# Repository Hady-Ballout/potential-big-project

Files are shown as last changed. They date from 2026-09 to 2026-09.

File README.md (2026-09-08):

# Interphone project

ESP32 door-entry prototype with QR visitor access, a resident web app, a Supabase backend, and hardware designs.

- [Software, firmware, and setup instructions](interphone/README.md)
- [Software plan](interphone/docs/PLAN.md)
- [Hardware brief](interphone/docs/PROJECT_CONTEXT.md)

The root folder contains the Fritzing drawings, exported wiring netlists, component list, and shopping list. Hardware operation has been verified; cloud-to-hardware integration and video/audio calling remain to be completed.

Local credentials, dependency folders, generated builds, and the discard folder are excluded from version control. Copy the supplied example configuration files when setting up a new machine.

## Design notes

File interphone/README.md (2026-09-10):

# Interphone

Cloud-connected door entry for apartment buildings. A visitor scans the QR sticker at the door,
picks an apartment, and the resident sees and hears them on their phone and taps **Unlock**.
An ESP32 at the door pulses a relay that opens a 12 V lock.

Full design: [docs/PLAN.md](docs/PLAN.md). Hardware brief: [docs/PROJECT_CONTEXT.md](docs/PROJECT_CONTEXT.md).

```
visitor phone ──HTTPS──▶ Supabase (Postgres + edge functions + realtime) ◀──push/realtime── resident PWA
                                  ▲ 1 s HTTPS poll, device token
                            ESP32 DevKit V1 firmware (relay, buzzer, LED, button)
```

## What is done (Phase 1 to 3)

| Piece | Where | Status |
|---|---|---|
| Firmware state machine, buzzer patterns, pin maps | `firmware/src` | done, 12 native unit tests pass |
| Wi-Fi + backend polling on a FreeRTOS task | `firmware/src/net_client.cpp` | done, compile-checked; needs the real build (`pio run`) |
| Wokwi breadboard simulation | `firmware/wokwi` | done |
| Database schema, RLS, demo seed | `supabase/migrations`, `supabase/seed.sql` | done, applied + RLS tested on Postgres 16 |
| Edge functions `ring`, `respond`, `device-poll` | `supabase/functions` | done, `deno check` clean |
| Virtual door controller (no hardware) | `tools/virtual-device` | done |
| Visitor page + resident app + push (minimal) | `web/` | done, see `web/README.md` |
| Door sticker QR generator | `tools/make-qr` | done |
| WebRTC video/audio + private signaling | `web/src/lib/webrtc.ts`, `supabase/functions/call-config` | done; needs TURN credentials and two-device field test |

## Quick start

### 1. Firmware on your laptop (no hardware)

```
cd firmware
pio test -e native          # unit tests for the door logic
pio run  -e esp32devkit     # full ESP32 build (needs the PlatformIO ESP32 toolchain, downloads once)
```
Then follow `firmware/wokwi/README.md` to press the button and watch the relay in the browser.

Serial keys while it runs (Wokwi or real board): `u` unlock, `d` deny, `s` status.

### 2. Backend locally

Requires Docker Desktop. The Supabase CLI runs through npx (or `scoop install supabase`).
```
npx supabase start                                    # local Postgres, auth, functions, studio (pulls images once)
npx supabase db reset                                 # applies migrations + seed.sql
npx supabase functions serve --env-file supabase/.env # (copy supabase/.env.example first; VAPID keys optional)
```
Demo data from `seed.sql`: building **demo-building** with apartments 1A–3A,
resident **demo@interphone.local / demo1234** (1A), device token **demo-device-token-change-me**.

### 3. See a cloud unlock reach the door

Terminal A — the door:
```
cd tools/virtual-device
SUPABASE_FUNCTIONS_URL=http://127.0.0.1:54321/functions/v1 DEVICE_TOKEN=demo-device-token-change-me node index.mjs
```
Terminal B — a visitor rings 1A, then the resident unlocks:
```
F=http://127.0.0.1:54321/functions/v1
curl "$F/ring?building=demo-building"                        # apartments + door_online
curl -X POST $F/ring -H 'content-type: application/json' \
     -d '{"building":"demo-building","apartment_id":"00000000-0000-0000-0000-00000000a001","note":"DHL"}'
# -> {"visit_id":"...","status":"ringing"}

# log in as the resident to get a JWT (anon key is printed by `supabase start`)
TOKEN=$(curl -s -X POST http://127.0.0.1:54321/auth/v1/token?grant_type=password \
  -H "apikey: $ANON_KEY" -H 'content-type: application/json' \
  -d '{"email":"demo@interphone.local","password":"demo1234"}' | jq -r .access_token)

curl -X POST $F/respond -H "authorization: Bearer $TOKEN" -H 'content-type: application/json' \
     -d '{"visit_id":"<visit_id from above>","action":"unlock"}'
```
Within a second terminal A prints `door -> UNLOCKING *** RELAY ON ***`.
To do the same with the simulated ESP32 instead, put your project's functions URL and the device
token in `firmware/secrets.ini` (see `secrets.ini.example`) and run Wokwi in VS Code — the Wokwi
browser editor cannot reach a `localhost` backend, so for the browser use a deployed Supabase project.

### 4. Web app: scan, ring, unlock

```
cd web && npm install && cp .env.example .env.local   # fill VITE_SUPABASE_ANON_KEY from `npx supabase status`
npm run dev                                           # http://localhost:5173
```
Visitor page: http://localhost:5173/d/demo-building. Resident app: http://localhost:5173/app
(demo@interphone.local / demo1234). With the virtual device from step 3 running, tapping **UNLOCK**
prints `RELAY ON` in terminal A. Door sticker: `node tools/make-qr/index.mjs demo-building http://<laptop LAN IP>:5173`.
Details, phone testing and push setup: `web/README.md`.

### 5. Deploy the backend to Supabase cloud

```
supabase link --project-ref <ref>
supabase db push
supabase functions deploy ring respond device-poll call-config
supabase secrets set --env-file supabase/.env
```

## API (edge functions)

| Function | Auth | Purpose |
|---|---|---|
| `GET /ring?building=slug` | none | apartments list + door online flag (visitor page) |
| `GET /ring?visit=id` | none | visit status, visitor polls while waiting |
| `POST /ring` | none, rate-limited | create a visit, push residents |
| `POST /respond` | resident JWT | `answer`, `unlock`, `deny` a visit; `unlock` with `apartment_id` for self-entry |
| `POST /device-poll` | `x-device-token` | door controller heartbeat + pending commands |

## Repository layout

```
firmware/   PlatformIO project (ESP32 DevKit V1 default, ESP32-S3 alternate, native tests)
supabase/   migrations, seed, edge functions, config
web/        visitor page + resident app (Vite + React), see web/README.md
tools/      virtual-device (fake door controller), make-qr (door sticker), docker-pull-host (image pull workaround)
docs/       PLAN.md, PROJECT_CONTEXT.md (hardware)
```

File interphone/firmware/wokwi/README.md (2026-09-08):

# Wokwi simulation

Two ways to run the firmware with no hardware.

## A. wokwi.com in the browser (no toolchain needed)

1. Run `python pack_for_browser.py` in this folder. It creates `browser-project/` with a
   flat copy of the firmware, a `sketch.ino`, `libraries.txt` and this `diagram.json`.
2. Go to https://wokwi.com -> New Project -> ESP32.
3. In the Wokwi editor, use the file menu to upload every file from `browser-project/`
   (or drag-and-drop them). Overwrite `sketch.ino` and `diagram.json` when asked.
4. Press the green Start button. In the serial monitor you should see the banner and
   `[door] -> IDLE` (standalone mode: no backend URL is configured, so the device counts as online).
5. Click the green pushbutton: LED2 blinks fast and the buzzer plays the ring pattern,
   then after 1 s the relay clicks, LED1 (on the relay contacts) lights for 3 s, LED2 is solid.
6. Type `u` in the serial monitor to simulate a cloud unlock, `d` for deny, `s` for status.

## B. Wokwi extension in VS Code (uses the real PlatformIO build)

1. Install the "Wokwi Simulator" VS Code extension and request the free license key it asks for.
2. `pio run -e esp32devkit`
3. F1 -> "Wokwi: Start Simulator" (it reads `wokwi.toml`).

## Differences from the real breadboard

- Wokwi has no NPN transistor or diode parts, so the buzzer is driven straight from GPIO18.
  On the real board GPIO18 -> 1k -> NPN base, buzzer on the collector with the 1N4007 flyback
  diode. The firmware is identical: a HIGH on the pin means sound in both cases.
- Wokwi has no 30-pin "DevKit V1" board with real 5V on VIN; power rails are logical here.
- LED1 on the relay's NO contact stands in for the 12V lock, exactly like the bench build.

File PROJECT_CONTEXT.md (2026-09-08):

# Interphone Project Two

Door entry / interphone controller built on an ESP32 dev board. Breadboard prototype
stage. Source of truth for the wiring is the Fritzing sketch and its exported netlist.

Last updated: 2026-09-01

---

## 1. What it does

A visitor or resident presses a button. The controller sounds a buzzer, shows status on
an LED, and fires a relay that would drive the electric door strike. On the current
breadboard build the strike is replaced by a resistor and LED on the relay contacts so
the actuation is visible on the bench.

Four functional blocks:

1. **Button input.** Tactile pushbutton with a 10k pull-up to 3V3. Active low: the GPIO
   reads HIGH at idle and LOW when pressed.
2. **Relay output.** GPIO drives the relay module IN pin. COM sits on the 5V rail, NO
   feeds 330R into an LED to ground. NC unconnected.
3. **Buzzer driver.** GPIO through 1k into the base of an NPN. Emitter to ground,
   collector to the buzzer, buzzer other side to the 5V rail, flyback diode across it.
   Low side switch.
4. **Status LED.** GPIO through 330R into an LED to ground, driven directly.

---

## 2. Bill of materials (from the netlist)

| Ref | Component | Qty |
|---|---|---|
| M1 | ESP32 dev board | 1 |
| Part1 | KY-019 5V relay module | 1 |
| J1 | Buzzer | 1 |
| D1 | Rectifier diode (1N4007) | 1 |
| Q1 | NPN transistor (2N2222 / BC547) | 1 |
| S1 | Tactile pushbutton, 4 pin | 1 |
| LED1 | Red LED 5mm (relay indicator) | 1 |
| LED2 | Red LED 5mm (status) | 1 |
| R1 | 330R (LED1 series) | 1 |
| R2 | 330R (LED2 series) | 1 |
| R3 | 10k (button pull-up) | 1 |
| R4 | 1k (transistor base) | 1 |
| Breadboard1 | RSR 03MB102 breadboard, 830 point | 1 |

12 components plus the breadboard.

---

## 3. Power rails

| Rail | Source | Feeds |
|---|---|---|
| 3V3 | Board 3V3 pins | R3 pull-up |
| 5V | Board 5V / VIN pin | Relay coil VCC, relay COM, buzzer, D1 cathode |
| GND | Board GND pins, both breadboard minus rails tied together | Everything |

Current budget on the 5V rail is roughly 70 to 80 mA for the relay coil plus about
30 mA for the buzzer. That is inside USB limits but coil inrush coinciding with a Wi-Fi
transmit burst is the likely cause of any brownout resets. Mitigation: 1000uF bulk cap
on the rail, 100nF decoupling near the relay and buzzer, and a 5V 2A wall adapter rather
than a laptop port.

---

## 4. Pin mapping

### 4a. Original design: ESP32-S3-DevKitC-1-N8R8

The Fritzing part numbers pins DIP style: 1 to 22 down the left header (J1), then 23 to
44 back up the right header (J3). Verified against the Espressif v1.1 header tables.

| Netlist pin | Actual pin | Use |
|---|---|---|
| 1, 2 | 3V3, 3V3 | 3V3 rail |
| 21 | 5V | 5V rail |
| 22, 23, 24, 44 | GND x4 | ground rails |
| 5 | GPIO5 | Relay IN |
| 6 | GPIO6 | Status LED via R2 |
| 11 | GPIO18 | Buzzer via R4 into Q1 base |
| 27 | GPIO21 | Pushbutton input |

GPIO5, 6, 18 and 21 are all plain I/O on the S3. No strapping, boot, USB or PSRAM
conflicts. GPIO43 and 44 are untouched, so UART0 and flashing stay intact.

**Status: verified functional as drawn.**

### 4b. Fallback: classic ESP32 DevKit V1 (ESP32-WROOM-32, 30 pin)

Only needed if the S3 stays out of stock. Different chip, so the netlist pin mapping
does not carry over and the Fritzing part must be swapped.

| Function | S3 | DevKit V1 |
|---|---|---|
| Relay IN | GPIO5 | GPIO5 |
| Status LED | GPIO6 | GPIO4 |
| Buzzer | GPIO18 | GPIO18 |
| Button | GPIO21 | GPIO19 |

Constraints on the classic ESP32: avoid GPIO6 to 11 (flash), avoid GPIO0, 2, 12 and 15
(strapping), GPIO34 to 39 are input only. The 5V pin is labelled VIN and sits around
4.6 to 4.7V on USB power after the protection diode, which is marginal but usually
enough for the relay coil.

---

## 5. Design notes and things to verify on hardware

- **Relay COM on the logic 5V rail.** Correct for the bench stand-in. For the real
  installation, COM goes to the door strike supply and stays isolated from the logic
  side. Do not carry this over to the final build.
- **Clone boards.** If the board is a clone rather than a genuine Espressif DevKitC-1
  (tell by the connector: genuine is Micro-B, clones often use dual USB-C), meter the
  header before wiring. Confirm the 5V pin and all four GND pins, since the rails hang
  off them.
- **Relay trigger threshold.** Most KY-019 boards trigger fine from a 3.3V GPIO. If it
  is stubborn, that is the threshold, not the wiring.
- **Buzzer type.** Circuit assumes an active 5V buzzer. A passive one needs a PWM tone
  on the GPIO instead of a simple HIGH.
- **Arduino IDE settings for S3 N16R8 clones:** board = ESP32S3 Dev Module, flash 16MB,
  PSRAM = OPI. Wrong PSRAM setting causes boot loops.

---

## 6. Procurement

Local supplier: Electroslab (Lebanon), also reachable on WhatsApp.

| Board | Price | Status |
|---|---|---|
| ESP32-S3 N16R8 dev board (clone, dual USB-C) | $12.00 | Out of stock, notify list |
| ESP32 DevKit V1 (WROOM-32, 30 pin) | $9.00 | In stock |

Full prototype kit including spares, debug gear and a second board estimates at $110 to
$195 cash USD locally, or $90 to $155 if the lab already has a multimeter. Ordering the
dev boards from AliExpress saves roughly $25 but adds three to six weeks.

Cables: genuine DevKitC-1 is Micro-B, the Electroslab S3 clone is USB-C, the DevKit V1
is Micro-B. Data cables, not charge only.

---

## 7. Optional expansion

- **Real door hardware:** 12V electric strike, 12V 2A supply, spade or screw terminals.
  Roughly $35 to $80. Keep that supply completely separate from the ESP32 5V rail.
- **On-device QR scanning:** requires an ESP32-S3 board with a camera. The DevKitC-1 has
  no imager. If the QR is scanned on the visitor's phone instead, no extra hardware is
  needed and the DevKit V1 is sufficient.

---

## 8. PCB Pilot coverage

Every component in this design exists in the PCB Pilot registry:

`esp32`, `relay_module`, `buzzer`, `diode`, `led`, `bjt_npn`, `pushbutton`, `resistor`.

The `esp32` kind is 12 pins, fixed order: 3V3, GND, VIN, EN, GPIO2, GPIO4, GPIO5,
GPIO13, GPIO18, GPIO19, GPIO21, GPIO22. Flagged `mcu` and `wiringOnly`, so it is
excluded from the SPICE deck but participates in layout and the topology rules.
`relay_module` pin order is VCC, GND, IN, COM, NO, NC, matching the KY-019.

**Registry gap:** there is no `esp32_s3` kind. Only classic ESP32, Arduino Uno and
Raspberry Pi are available under `mcu`. The `esp32` kind also exposes only 8 GPIOs,
which is enough for this project but tight. Worth logging as a product item given how
common S3 boards are in student work.

---

## 9. Open items

- [ ] Confirm S3 restock date with Electroslab, or commit to the DevKit V1 fallback
- [ ] Meter the board header (5V pin, all GND pins) before wiring
- [ ] Decide whether QR scanning happens on device or on the visitor's phone
- [ ] Confirm with instructor whether the demo needs a real strike or the LED stand-in
- [ ] Firmware: button debounce, relay pulse duration, buzzer pattern, Wi-Fi provisioning
- [ ] Run the design through PCB Pilot `validate_circuit` as a toolchain smoke test

---

## 10. Files

| File | What it is |
|---|---|
| `Interphone_Project_two_netlist.xml` | Fritzing netlist export, source of truth for wiring |
| `Interphone Project two.fzz` | Fritzing sketch |
| `PROJECT_CONTEXT.md` | This file |

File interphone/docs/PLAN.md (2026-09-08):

# Interphone software plan — build everything before the hardware arrives

## Context

The hardware for the ESP32 door-entry controller is ordered but not here yet (DevKit V1, KY-019 relay, 12V solenoid lock, buzzer, LEDs — see `Component List.xlsx`). The goal is to start the software now and have as much as possible working, tested and demoable by the time the parts arrive, so hardware bring-up becomes a short checklist rather than the start of development.

Scope confirmed with Hady: **everything from the moment the visitor scans the QR code** —

1. Visitor scans a QR sticker at the building door → a web page opens on their phone.
2. Visitor picks the apartment they're visiting → the resident gets a push notification.
3. Resident opens the app, **sees and hears the visitor (video + audio)**, and taps Unlock.
4. The ESP32 at the door pulses the relay → the 12V lock opens; buzzer + LED give feedback at the door.

Decisions: PlatformIO in VS Code for firmware, Wokwi in the browser for simulation, Supabase for the backend, an installable web app (PWA) with push notifications for residents. Purpose: portfolio / startup prototype, so it should look and behave like a product, and the architecture should have a credible path to a real multi-building deployment.

Key design choice for video/audio: **the visitor's own phone is the intercom panel.** They already scanned the QR with it, so a browser-to-browser WebRTC call (visitor page ↔ resident PWA) gives video + audio with zero extra hardware. The DevKit V1 has no camera or mic, and an ESP32-CAM would give worse video for more work. A door-mounted camera can be a later product phase.

---

## Architecture

```
 Visitor phone                 Supabase (cloud)                 Resident phone
 ┌──────────────┐    HTTPS     ┌─────────────────────┐   push    ┌──────────────┐
 │ /d/{building}│─────────────▶│ Edge fn: ring       │──────────▶│ Resident PWA │
 │ pick apt,    │              │ Postgres + RLS      │  realtime │ incoming call│
 │ ring, camera │◀════════════▶│ Realtime (signaling)│◀═════════▶│ video+audio  │
 └──────────────┘   WebRTC     │ Edge fn: unlock     │           │ [Unlock]     │
        ▲ (P2P via STUN/TURN)  │ Edge fn: device-poll│           └──────────────┘
        └──────────────────────│ door_commands table │
                               └─────────┬───────────┘
                                         │ HTTPS poll (1 s), device token
                               ┌─────────▼───────────┐
                               │ ESP32 DevKit V1     │  GPIO5 relay → 12V lock
                               │ firmware            │  GPIO18 buzzer, GPIO4 LED
                               │ (Wokwi until real)  │  GPIO19 button (exit/test)
                               └─────────────────────┘
```

ESP32 ↔ backend uses **short polling over HTTPS** first (1 s interval, ≤1 s unlock latency). Reasons: trivial firmware, works in Wokwi's simulated Wi-Fi, no websocket/Phoenix protocol on the microcontroller. Upgrading to Supabase Realtime or MQTT later is a contained change inside `net_client`.

Multi-apartment from day one: one ESP32 per building door, many apartments per building, many residents per apartment. The visitor page is per building (`/d/{building_slug}`), which is what the QR encodes.

---

## Repository layout (new monorepo `interphone/` inside "Potential Big Project")

```
interphone/
  README.md
  firmware/                      PlatformIO project
    platformio.ini               envs: esp32devkit (default), esp32s3 (kept), native (tests)
    include/pins.h               #ifdef BOARD_DEVKIT_V1 / BOARD_ESP32_S3 pin maps
    include/config.h             timings, poll interval, Wi-Fi/device creds via build flags
    src/main.cpp                 setup/loop only: wires modules together
    src/door_controller.{h,cpp}  pure logic state machine (no Arduino deps) — unit-tested
    src/buzzer.{h,cpp}           non-blocking pattern player (ring / unlocked / denied / error)
    src/net_client.{h,cpp}       Wi-Fi connect, poll device-poll fn, ack commands, heartbeat
    src/hal.h                    tiny interface (digitalWrite/millis) so logic is mockable
    test/test_door_controller/   Unity tests run on the laptop (pio test -e native)
    wokwi/diagram.json           exact breadboard: DevKit V1, KY-019, buzzer+NPN+diode, LEDs, button
    wokwi/wokwi.toml
  supabase/
    config.toml
    migrations/0001_schema.sql   tables + RLS
    functions/ring/              public: create visit, notify residents
    functions/unlock/            resident-auth: insert door_command
    functions/device-poll/       device-token auth: return pending commands, record heartbeat
    functions/send-push/         Web Push (VAPID) helper used by ring
    seed.sql                     demo building, 3 apartments, 1 device, 1 resident
  web/                           Vite + React + TypeScript PWA (one app, two entry routes)
    src/routes/visitor/          /d/:slug → choose apartment → ringing → call → door opened
    src/routes/resident/         /app → login (magic link) → incoming visit → video → Unlock → history
    src/lib/supabase.ts, webrtc.ts, push.ts
    public/sw.js                 service worker: push + PWA install
  tools/
    virtual-device/              Node script that polls exactly like the firmware and prints UNLOCK
    make-qr/                     generates the door QR PNG for a building slug
```

---

## Data model (Supabase Postgres)

| Table | Key columns | Notes |
|---|---|---|
| `buildings` | id, slug, name | slug is what the QR encodes |
| `apartments` | id, building_id, label ("3B"), sort_order | shown on visitor page |
| `profiles` | id (= auth.users.id), display_name | |
| `apartment_members` | apartment_id, profile_id, role | who can unlock which door |
| `devices` | id, building_id, name, token_hash, last_seen_at | one per door controller |
| `visits` | id, apartment_id, status, visitor_note, created_at, answered_by, ended_at | status: `ringing → answered → unlocked / denied / expired` |
| `door_commands` | id, device_id, visit_id, action ("unlock"), created_at, delivered_at, expires_at | firmware acks by setting delivered_at; expires after 30 s |
| `push_subscriptions` | profile_id, endpoint, keys | Web Push targets |

RLS: residents read/write only visits for apartments they belong to; visitor page uses the `ring` edge function (service role, rate-limited by IP + apartment); devices never touch the DB directly — only `device-poll` with a hashed token.

WebRTC signaling: a Supabase Realtime **Broadcast** channel per visit (`visit:{id}`) carries SDP offers/answers and ICE candidates. STUN: Google public. TURN: Metered.ca free tier (needed for phones on carrier NAT); coturn on a VPS later.

---

## Firmware behaviour (door_controller state machine)

```
IDLE ──button pressed (debounced 30 ms)──▶ LOCAL_RING  (buzzer ring pattern, LED blink; for bench demo also unlocks after 1 s)
IDLE ──unlock command from cloud───────▶ UNLOCKING   (relay HIGH for UNLOCK_MS=3000, buzzer "unlocked" chirp, LED solid)
UNLOCKING ──timer──────────────────────▶ COOLDOWN    (relay LOW, ignore new unlocks for 1 s)
COOLDOWN ──timer───────────────────────▶ IDLE
any ──Wi-Fi lost──────────────────────▶ OFFLINE      (LED slow blink; button still works locally) ──reconnected──▶ IDLE
```

Everything non-blocking (`millis()`-based), no `delay()` in loop. The state machine takes `now_ms` and events as plain C++ so `pio test -e native` runs it on the laptop with no board.

Pin map (`pins.h`), DevKit V1 default per `PROJECT_CONTEXT.md` §4b: relay GPIO5, LED GPIO4, buzzer GPIO18, button GPIO19 (INPUT_PULLUP, active low). S3 map kept behind `#ifdef` so the original design isn't lost.

---

## Phases (each ends with something you can see working)

### Phase 0 — Setup (½ day)
Install VS Code + PlatformIO, Node 20, Supabase CLI; create Supabase project and Wokwi account; `git init` the monorepo. Commit the existing `PROJECT_CONTEXT.md` into `docs/` and update it: DevKit V1 is now primary, S3 is the alternate, `interphone 3.fzz` listed.

### Phase 1 — Firmware core in Wokwi (1–2 days) ← **"see the relay click today"**
`pins.h`, `door_controller`, `buzzer`, `main.cpp`, `diagram.json`. Press the simulated button → buzzer sounds, LED blinks, relay clicks and its LED lights for 3 s. Native unit tests for debounce, unlock pulse length, cooldown, and re-trigger rejection.

### Phase 2 — Backend + cloud unlock (2 days)
`0001_schema.sql`, RLS, `seed.sql`, edge functions `ring`, `unlock`, `device-poll`. `tools/virtual-device` polls and prints UNLOCK. Then `net_client` in firmware: Wokwi ESP32 joins `Wokwi-GUEST`, polls `device-poll` over HTTPS. Demo: `curl` the `unlock` function → simulated relay fires within a second.

### Phase 3 — Visitor page + resident PWA + push (3–4 days)

_Status (2026-09-05): built in a minimal form — email+password login instead of magic link, no visit history yet, video deferred to Phase 4. See `web/README.md`._
Visitor: `/d/demo-building` → apartment grid → "Ring" → "Waiting for resident…" → status updates via Realtime. Resident: magic-link login, installable PWA, push notification on ring, incoming-visit screen with Unlock / Deny, visit history. `make-qr` produces the sticker PNG. Demo: scan QR on a phone, ring, get push on another phone, tap Unlock, Wokwi relay fires.

### Phase 4 — Video + audio (2–3 days)
`webrtc.ts`: visitor page requests camera+mic on "Ring"; on resident answer, exchange SDP/ICE over the `visit:{id}` Broadcast channel; resident sees/hears visitor (one-way video, two-way audio). Hang-up on unlock/deny/expiry. TURN credentials fetched from an edge function so keys aren't in the client.

### Phase 5 — Product hardening (ongoing)
Device online/offline indicator from `last_seen_at`; visit auto-expire after 60 s; rate-limit `ring`; audit log of unlocks; Wi-Fi provisioning via captive portal (WiFiManager) instead of compiled-in creds; OTA updates; building admin screen to manage apartments/residents.

### When the components arrive — bring-up checklist (not software, but planned now)
- Meter the DevKit V1 header (VIN, all GNDs) before wiring.
- Flash the same firmware with `-e esp32devkit`; only `pins.h` matters.
- Verify KY-019 triggers from 3.3 V GPIO; verify buzzer is active (it is per shopping list).
- **12V lock wiring:** lock supply (12V/1A adapter) is completely separate from ESP32 5V. Relay COM → +12V, NO → lock +, lock − → 12V GND. **Add a 1N4007 flyback diode across the solenoid** (cathode to +12V) — the shopping list has the diodes but `PROJECT_CONTEXT.md` only puts one on the buzzer. The lock is a solenoid and will spike the relay contacts without it.
- Watch for brownout resets on relay inrush + Wi-Fi burst (1000 µF bulk cap, wall adapter not laptop USB).

---

## Verification

- **Firmware logic:** `pio test -e native` — debounce, 3 s unlock pulse, cooldown, offline behaviour.
- **Firmware build:** `pio run -e esp32devkit` compiles clean; upload `.pio/build/esp32devkit/firmware.bin` + `diagram.json` to wokwi.com and drive the button.
- **Backend:** `supabase start` locally, `supabase db reset` applies migrations + seed; `supabase functions serve`; `curl` each function; RLS checked by attempting cross-apartment unlock as a second seeded user (must fail).
- **End-to-end without hardware:** virtual-device running → visitor page on phone → resident PWA on second phone/browser → Unlock → virtual device prints UNLOCK; then the same with Wokwi instead of virtual device.
- **Video:** two phones on different networks (Wi-Fi vs mobile data) to prove TURN works.

## Out of scope for now
Door-mounted camera (ESP32-CAM / S3-CAM), native iOS/Android apps, payments/subscriptions, multi-door per building, NFC/keypad. All fit the schema later without redesign.

## Open questions to settle during Phase 0 (not blocking)
- Physical button at the door: keep as a plain "exit/test" button, or make it a fallback bell that rings *all* apartments? (Plan assumes exit/test.)
- Web framework: plan assumes Vite + React + TypeScript; SvelteKit or Next.js are equally fine if you prefer.

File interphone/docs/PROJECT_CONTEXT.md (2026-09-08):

# Interphone — hardware brief

Door entry / interphone controller built on an ESP32 dev board. Breadboard prototype stage;
the software is being built ahead of the hardware (see PLAN.md).

Last updated: 2026-09-02. Supersedes the copy in the parent folder.

---

## 1. What it does

A visitor rings from their phone (QR at the door) or presses the door button. The controller
sounds a buzzer, shows status on an LED, and fires a relay that drives the electric lock. On the
breadboard build the lock is replaced by a resistor and LED on the relay contacts so the
actuation is visible on the bench.

Four functional blocks:

1. **Button input.** Tactile pushbutton with a 10k pull-up to 3V3. Active low.
2. **Relay output.** GPIO drives the relay module IN pin. Bench: COM on the 5V rail, NO feeds
   330R into an LED to ground. Real door: COM on +12V, NO to the lock (see §5).
3. **Buzzer driver.** GPIO through 1k into the base of an NPN. Emitter to ground, collector to the
   buzzer, buzzer other side to the 5V rail, flyback diode across it. Low-side switch.
4. **Status LED.** GPIO through 330R into an LED to ground, driven directly.

---

## 2. Bill of materials

What was actually ordered (`Component List.xlsx` / `Interphone_Shopping_List_v2.pdf`, $32.51,
BEC + Electroslab):

| Ref | Component | Qty |
|---|---|---|
| M1 | **ESP32 DevKit V1 (30-pin, WROOM-32)** | 1 |
| Part1 | KY-019 5V relay module | 2 (1 spare) |
| J1 | Active buzzer 5V | 2 |
| D1 | 1N4007 rectifier diode | 10 |
| Q1 | NPN transistor 2SC2061 | 2 |
| S1 | Tactile pushbutton 12×12 | 5 |
| LED1, LED2 | Red LED 5mm | 5 |
| R1, R2 | 330R | 2 |
| R3 | 10k | 1 |
| R4 | 1k | 1 |
| — | 12V solenoid door lock 55×28×30 | 1 |
| — | 12V / 1A wall adapter + 2× barrel jack | 1 |
| — | Breadboard 830, jumper wire, Micro-USB cable | — |

The ESP32-S3 (original design) was out of stock; the DevKit V1 is now the primary board.

---

## 3. Power rails

| Rail | Source | Feeds |
|---|---|---|
| 3V3 | Board 3V3 pin | R3 pull-up |
| 5V | Board VIN pin (USB) | Relay coil VCC, relay COM (bench only), buzzer, D1 cathode |
| 12V | Wall adapter | **Lock only**, via the relay contacts. Never tied to the ESP32 rails except GND. |
| GND | Board GND pins + adapter minus | Everything |

5V rail budget: ~70–80 mA relay coil + ~30 mA buzzer. Coil inrush during a Wi-Fi burst is the
likely cause of any brownout reset. Mitigation: 1000 µF bulk cap on the rail, 100 nF near the relay
and buzzer, and a wall adapter rather than a laptop USB port. On the DevKit V1, VIN sits around
4.6–4.7 V on USB after the protection diode — marginal but usually enough for the KY-019.

---

## 4. Pin mapping (matches `firmware/src/pins.h`)

| Function | DevKit V1 (primary) | ESP32-S3 (alternate) |
|---|---|---|
| Relay IN | GPIO5 | GPIO5 |
| Status LED | GPIO4 | GPIO6 |
| Buzzer (NPN base) | GPIO18 | GPIO18 |
| Button (active low) | GPIO19 | GPIO21 |

DevKit V1 constraints: avoid GPIO6–11 (flash), GPIO0/2/12/15 (strapping); GPIO34–39 input only.
S3 notes: GPIO43/44 untouched so UART0 and flashing stay intact. Arduino settings for S3 N16R8
clones: board = ESP32S3 Dev Module, flash 16MB, PSRAM = OPI.

Fritzing: `interphone 3.fzz` (2026-08-28) is the sketch with the DevKit V1 part;
`Interphone Project two.fzz` + `_netlist.xml` are the S3 version.

---

## 5. Real lock wiring (when the demo moves off the bench)

```
12V adapter +  ──── relay COM
relay NO       ──── lock +
lock −         ──── 12V adapter −  ──── ESP32 GND (common ground only)
1N4007 across the lock: cathode (band) to lock +, anode to lock −
```
- **The flyback diode across the solenoid is mandatory.** The shopping list has ten 1N4007s;
  the original brief only put one on the buzzer. Without it the coil kick arcs the relay contacts
  and can reset the ESP32.
- The 12V supply never touches the ESP32 5V/3V3 rails. Relay contacts are the isolation.
- A 12V solenoid lock draws ~0.5–1 A while energised; the 1 A adapter is at its limit. Keep
  `UNLOCK_MS` at 3 s or less (firmware default) and don't hold it.
- Relay COM on the logic 5V rail is a bench convenience only. Do not carry it to the final build.

---

## 6. Bring-up checklist (hardware arrival)

- [ ] Meter the DevKit V1 header: VIN, 3V3, all GND pins, before wiring anything.
- [ ] `pio run -e esp32devkit -t upload`, open the serial monitor, confirm the banner and `-> IDLE`.
- [ ] Press the button: ring pattern, LED blink, relay click, LED1 3 s.
- [ ] Type `u` in the serial monitor: same without the button.
- [ ] Confirm the KY-019 triggers from the 3.3 V GPIO. If not, it's the module threshold, not wiring.
- [ ] Confirm the buzzer is active (it should be; passive needs `tone()` — see `buzzer.h`).
- [ ] Put Wi-Fi + device token in `firmware/secrets.ini`, watch `[net] backend online`, unlock from the app.
- [ ] Watch for resets when the relay fires during Wi-Fi traffic → add the bulk cap.
- [ ] Only then wire the 12V lock per §5.

---

## 7. Procurement notes

Electroslab (Lebanon, WhatsApp) — DevKit V1 $9 in stock; S3 N16R8 clone $12 out of stock.
BEC — everything else. Cables: DevKit V1 is Micro-B, data cable not charge-only.

## 8. Optional expansion

- Door camera: needs an ESP32-S3 with camera or a separate cam. The product design instead uses
  the visitor's own phone camera via WebRTC (PLAN.md Phase 4), so no door camera is required.
- NFC / keypad / second door: fit the schema (`devices` per building) without redesign.

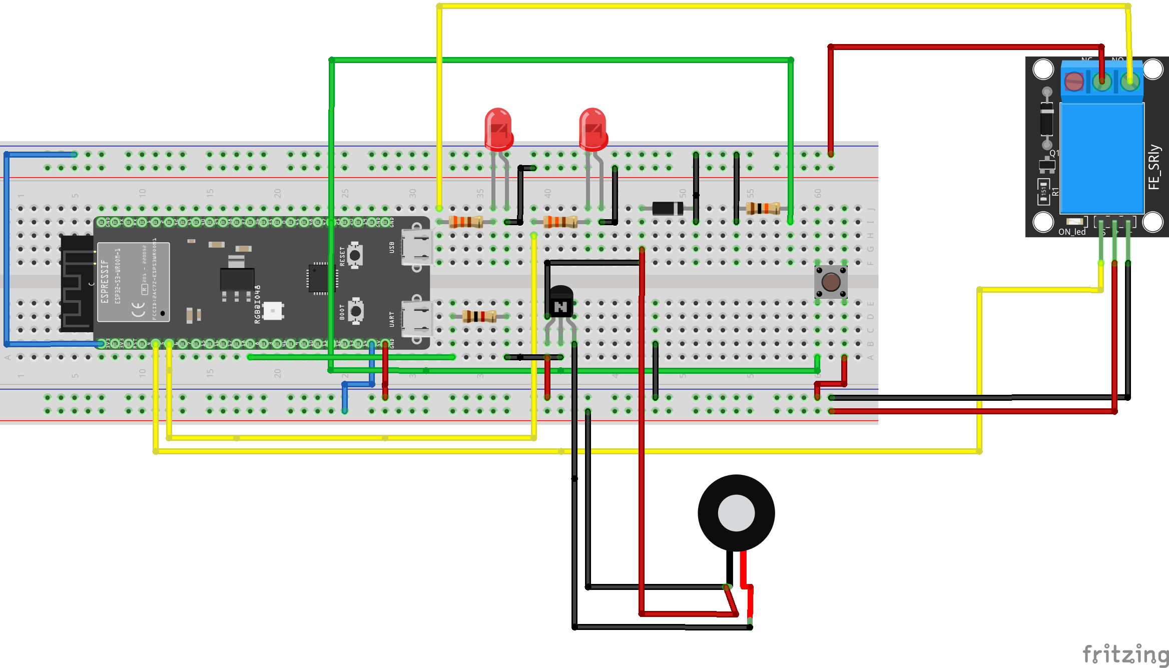
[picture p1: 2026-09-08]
Interphone Project one_bb.png

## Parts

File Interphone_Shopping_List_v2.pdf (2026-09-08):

# | Component | Qty | Unit Price ($) | Line Total ($)

1 | 12V Solenoid Door Lock (55×28×30 mm) | 1 | $7.00 | $7.00
2 | ESP32 DevKit V1 (30-pin, WROOM-32) | 1 | $9.00 | $9.00
3 | Active Buzzer (5 V) | 2 | $0.33 | $0.66
4 | NPN Transistor 2SC2061 (80 V, 0.7 A) | 2 | $0.60 | $1.20
5 | Rectifier Diode 1N4007 (5-pack) | 2 | $0.25 | $0.50
6 | Red LED 5 mm (5-pack) | 1 | $0.20 | $0.20
7 | Resistor 330 Ω, 0.25 W | 2 | $0.10 | $0.20
8 | Resistor 10 kΩ, 0.25 W | 1 | $0.10 | $0.10
9 | Resistor 1 kΩ, 0.25 W | 1 | $0.10 | $0.10
10 | Tactile Push Button 12×12 mm (5-pack) | 1 | $0.50 | $0.50
11 | Breadboard 830 points, solderless | 1 | $1.50 | $1.50
12 | KY-019 5 V Relay Module (1-channel) | 2 | $0.60 | $1.20
13 | 12 V / 1 A Wall Adapter | 1 | $3.00 | $3.00
14 | Jumper Wire (30 AWG spool, 230 m) | 1 | $4.75 | $4.75
15 | Micro-USB Cable 1 m | 1 | $2.00 | $2.00
16 | DC Barrel Jack Adapter (female, 5.5×2.1 mm) | 2 | $0.30 | $0.60
TOTAL | | | | $32.51

## Components

Store | Product Link
BEC | View product (https://bec-lb.com/products/dc-12v-cabinet-door-lock-electric-lock-assembly-solenoid-size-55-28-30mm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)
Electroslab | View product (https://electroslab.com/products/esp32?_pos=1&_sid=f5b40143a&_ss=r)
BEC | View product (https://bec-lb.com/products/5v-active-buzzer?_pos=1&_sid=24194e8b2&_ss=r)
BEC | View product (https://bec-lb.com/products/transistor-2sc2061-npn-80v-0-7a?_pos=1&_sid=d88fd3394&_ss=r)
BEC | View product (https://bec-lb.com/products/1n4007-dip-0-5w5pcs?_pos=9&_sid=3a8826af8&_ss=r)
BEC | View product (https://bec-lb.com/products/28mm-leg-led-5mm-red-5pcs?_pos=2&_sid=662e6963d&_ss=r)
BEC | View product (https://bec-lb.com/products/resistor-0-25w-330?_pos=1&_sid=8fc9f54b9&_ss=r)
BEC | View product (https://bec-lb.com/products/resistor-0-25w-10k?_pos=1&_sid=8a0e5cff8&_ss=r)
BEC | View product (https://bec-lb.com/products/resistor-0-25w-1k?_pos=2&_sid=920e417d1&_ss=r)
BEC | View product (https://bec-lb.com/products/12x12x7-3mm-tactile-push-button-switch-round-5-pcs-per-pack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)
BEC | View product (https://bec-lb.com/products/830-points-soldless-breadboard?_pos=1&_sid=ca9a9e97e&_ss=r)
BEC | View product (https://bec-lb.com/products/1-channel-relay-5v?_pos=1&_sid=533f5c4d6&_ss=r)
BEC | View product (https://bec-lb.com/products/adapter-12v-1a?_pos=1&_sid=2b74586f7&_ss=r)
BEC | View product (https://bec-lb.com/products/copper-wire-0-5mm-230m-30awg-yellow?_pos=13&_sid=343fd32aa&_ss=r)
BEC | View product (https://bec-lb.com/products/micro-usb-cable-1m-1?_pos=1&_sid=a554a0fee&_ss=r)
BEC | View product (https://bec-lb.com/products/dc-005-female-dc-power-jack-supply-socket-5-5x2-1mm?_pos=1&_sid=8453c3b67&_ss=r)

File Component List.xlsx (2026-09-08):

Components
# | Component | Qty | Unit Price ($) | Line Total ($) | Store | Product Link
1 | 12V Solenoid Door Lock (55×28×30 mm) | 1 | $7.00 | $7.00 | BEC | View product (https://bec-lb.com/products/dc-12v-cabinet-door-lock-electric-lock-assembly-solenoid-size-55-28-30mm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)
2 | ESP32 DevKit V1 (30-pin, WROOM-32) | 1 | $9.00 | $9.00 | Electroslab | View product (https://electroslab.com/products/esp32?_pos=1&_sid=f5b40143a&_ss=r)
3 | Active Buzzer (5 V) | 2 | $0.33 | $0.66 | BEC | View product (https://bec-lb.com/products/5v-active-buzzer?_pos=1&_sid=24194e8b2&_ss=r)
4 | NPN Transistor 2SC2061 (80 V, 0.7 A) | 2 | $0.60 | $1.20 | BEC | View product (https://bec-lb.com/products/transistor-2sc2061-npn-80v-0-7a?_pos=1&_sid=d88fd3394&_ss=r)
5 | Rectifier Diode 1N4007 (5-pack) | 2 | $0.25 | $0.50 | BEC | View product (https://bec-lb.com/products/1n4007-dip-0-5w5pcs?_pos=9&_sid=3a8826af8&_ss=r)
6 | Red LED 5 mm (5-pack) | 1 | $0.20 | $0.20 | BEC | View product (https://bec-lb.com/products/28mm-leg-led-5mm-red-5pcs?_pos=2&_sid=662e6963d&_ss=r)
7 | Resistor 330 Ω, 0.25 W | 2 | $0.10 | $0.20 | BEC | View product (https://bec-lb.com/products/resistor-0-25w-330?_pos=1&_sid=8fc9f54b9&_ss=r)
8 | Resistor 10 kΩ, 0.25 W | 1 | $0.10 | $0.10 | BEC | View product (https://bec-lb.com/products/resistor-0-25w-10k?_pos=1&_sid=8a0e5cff8&_ss=r)
9 | Resistor 1 kΩ, 0.25 W | 1 | $0.10 | $0.10 | BEC | View product (https://bec-lb.com/products/resistor-0-25w-1k?_pos=2&_sid=920e417d1&_ss=r)
10 | Tactile Push Button 12×12 mm (5-pack) | 1 | $0.50 | $0.50 | BEC | View product (https://bec-lb.com/products/12x12x7-3mm-tactile-push-button-switch-round-5-pcs-per-pack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)
11 | Breadboard 830 points, solderless | 1 | $1.50 | $1.50 | BEC | View product (https://bec-lb.com/products/830-points-soldless-breadboard?_pos=1&_sid=ca9a9e97e&_ss=r)
12 | KY-019 5 V Relay Module (1-channel) | 2 | $0.60 | $1.20 | BEC | View product (https://bec-lb.com/products/1-channel-relay-5v?_pos=1&_sid=533f5c4d6&_ss=r)
13 | 12 V / 1 A Wall Adapter | 1 | $3.00 | $3.00 | BEC | View product (https://bec-lb.com/products/adapter-12v-1a?_pos=1&_sid=2b74586f7&_ss=r)
14 | Jumper Wire (30 AWG spool, 230 m) | 1 | $4.75 | $4.75 | BEC | View product (https://bec-lb.com/products/copper-wire-0-5mm-230m-30awg-yellow?_pos=13&_sid=343fd32aa&_ss=r)
15 | Micro-USB Cable 1 m | 1 | $2.00 | $2.00 | BEC | View product (https://bec-lb.com/products/micro-usb-cable-1m-1?_pos=1&_sid=a554a0fee&_ss=r)
16 | DC Barrel Jack Adapter (female, 5.5×2.1 mm) | 2 | $0.30 | $0.60 | BEC | View product (https://bec-lb.com/products/dc-005-female-dc-power-jack-supply-socket-5-5x2-1mm?_pos=1&_sid=8453c3b67&_ss=r)
TOTAL |  |  |  | $32.51

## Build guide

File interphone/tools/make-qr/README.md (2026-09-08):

# make-qr — door sticker QR code

Generates the QR code visitors scan at the door. It encodes `<baseUrl>/d/<building-slug>`,
which opens the visitor page of the web app.

```
cd tools/make-qr
npm install
node index.mjs <building-slug> <baseUrl> [--out <file-without-extension>]

node index.mjs demo-building http://192.168.1.10:5173          # local demo, phone on the same Wi-Fi
node index.mjs demo-building https://interphone.example --out stickers/front-door
```

Writes `<out>.png` (1024 px, for printing) and `<out>.svg` (scalable). Default output is `./<slug>.png` and `.svg`.
The slug must match the `buildings.slug` rule (`a-z`, `0-9`, `-`, 3 to 40 chars).

The sticker artwork (building name, "scan to ring" text, logo) is not generated yet; drop the PNG into any label template.

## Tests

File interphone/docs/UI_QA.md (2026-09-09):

# Interphone UI release checks

The interface uses a warm light palette, shared controls, and centralized English copy. Visitor entry stays mobile-first; the resident home expands to two columns on desktop. No database migration or firmware update is required.

## Automated verification

Verified in this workspace: production build, 14 unit tests, and all 27 browser scenarios (including a focused rerun of the corrected authentication fixture). Automated axe scans found no violations in the tested login, visitor-selection, and incoming-visit screens at all four widths. Screenshots were visually inspected on mobile and desktop. Production dependency audit: zero reported vulnerabilities.

From `interphone/web`:

```sh
npm ci
npm test
npm run build
npm run test:ui
```

On Windows PowerShell with script execution disabled, use `npm.cmd` in place of `npm`. Browser tests use an installed Google Chrome by default. Set `PLAYWRIGHT_CHANNEL=msedge` to use an installed Microsoft Edge instead. They launch their own Vite server on `127.0.0.1:5174`; this port must be free.

**The browser suite uses a simulated backend, not the virtual controller or physical hardware.** Test configuration supplies fake backend credentials, intercepts all requests to that backend, and closes its realtime websocket locally. No test unlock is sent to a real entrance.

Coverage includes apartment selection, keyboard navigation, duplicate submissions, visitor outcomes, preserved form state, loading/errors, offline controls, stale-data recovery, accurate unlock language, expired/unavailable notification links, password visibility, and notification setup/permission guidance. Screenshots and axe accessibility scans cover login, visitor selection, and incoming visits at 360, 390, 768, and 1440 CSS pixels. A 720px viewport checks the reflow equivalent of a 1440px desktop at 200% zoom; it is not a native browser zoom or physical-phone test.

Screenshots and retained failure traces are written to `web/test-results/` and excluded from Git. SVG identity assets are source controlled. Run `npm run icons` after changing `public/icon.svg` to regenerate the two PNG Home Screen icons.

## Behavior to preserve

- Approval means an unlock request was queued. The UI must never infer physical opening, lock position, or relocking from a successful HTTP response or the existing firmware acknowledgement.
- Remote unlocking requires a fresh successful controller query and a recent heartbeat. A failed query preserves previous data, marks it stale, and disables actions until recovery. The visitor may still ring when the controller is offline.
- `/app/visit/:visitId` retains its target through sign-in and reads that visit within the resident's selected apartment and existing RLS. An ended or unavailable visit cannot silently switch to a different active visitor.
- SDK retries are disabled for dashboard reads because the UI owns polling and retry feedback. Requests have a 12-second timeout; the last successful state is retained across refresh errors.
- Notification support, browser permission, and backend configuration are separate conditions. A local browser subscription is only considered enabled when it also belongs to the signed-in resident in the backend.
- The existing single-apartment assumption remains. Membership selection is deterministic by apartment ID; multi-apartment switching is not included.

## Physical demo rehearsal — requires the prototype and two phones

These checks remain manual; automated browser success does not verify them.

1. Serve the app over HTTPS, confirm the real backend and controller are configured, and sign into the resident account on one phone.
2. Scan the entrance QR on the visitor phone, choose the apartment, and send a short message. Confirm the other phone displays the same request.
3. Tap Unlock entrance once. Confirm the UI says **Unlock request sent** / **Entry approved**, then separately observe the relay and lock. Record any latency or failed actuation.
4. Repeat with Decline and with no resident response. Verify the visitor receives the appropriate outcome.
5. Disconnect the controller and wait for its heartbeat to become stale. Unlock must be disabled; visitor ringing should still work. Restore the controller and verify recovery.
6. Interrupt the resident phone's connection. Confirm that existing visitor information remains visible with a stale/reconnecting notice, then recovers without a reload.
7. Enable real push notifications, background the resident app, ring again, and open the notification. Also open an old notification after its visit ends.
8. On iPhone/iPad, add the app to the Home Screen and open the installed app before testing notifications. Check the icon, browser permissions, safe areas, and software keyboard. Repeat the entry flow in Android Chrome.

## Human usability and accessibility acceptance

- Ask three first-time testers to ring an apartment and respond as a resident without coaching. Record completion, hesitation, wrong actions, and whether they understand approval versus verified physical opening.
- Test keyboard focus order, visible focus, and 200% browser zoom in the real browser. Check long building names and apartment labels on a narrow phone.
- Listen with VoiceOver or TalkBack: fields must have clear labels; selection must be announced; waiting/outcome transitions and newly arriving visitors must be understandable without seeing the screen. Automatic axe scans do not replace this check.
- Check notification available/enabled states with a real subscription. Automated checks cover blocked, unsupported, and unconfigured states without asking a browser for a real push subscription.

## Existing tooling note

The dependency audit reports advisories in the pre-existing Vitest 2 development-tool chain. Production dependency auditing is separate; this UI change does not introduce a Vitest UI server or perform a major test-runner migration.

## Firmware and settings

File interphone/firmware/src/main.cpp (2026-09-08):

// Interphone door controller — wiring only. Logic lives in door_controller / buzzer,
// networking in net_client. See README.md for the serial test commands.
#include <Arduino.h>
#include "pins.h"
#include "config.h"
#include "door_controller.h"
#include "buzzer.h"
#include "net_client.h"

static door::Controller ctl([] {
  door::Config c;
  c.debounce_ms = DEBOUNCE_MS;
  c.unlock_ms = UNLOCK_MS;
  c.cooldown_ms = COOLDOWN_MS;
  c.local_ring_ms = LOCAL_RING_MS;
  c.local_ring_unlocks = LOCAL_RING_UNLOCKS != 0;
  return c;
}());
static door::Buzzer buzzer;
static NetClient net;
static door::State last_state = door::State::Offline;  // so the first transition (-> IDLE) is logged

static void printStatus() {
  Serial.printf("[door] state=%s online=%d wifi=%d unlocks=%lu rejected=%lu err=\"%s\"\n",
                door::stateName(ctl.state()), net.online(), net.wifiConnected(),
                (unsigned long)ctl.unlockCount(), (unsigned long)ctl.rejectedUnlocks(),
                net.lastError());
}

static void handleSerial() {
  while (Serial.available()) {
    char ch = (char)Serial.read();
    switch (ch) {
      case 'u': Serial.println("[serial] unlock"); ctl.requestUnlock(); break;
      case 'd': Serial.println("[serial] deny");   ctl.requestDeny();   break;
      case 's': printStatus(); break;
      case 'h': case '?':
        Serial.println("keys: u=unlock  d=deny  s=status  (press the button for a local ring)");
        break;
      default: break;
    }
  }
}

void setup() {
  Serial.begin(115200);
  delay(200);
  Serial.printf("\nInterphone door controller v%s on %s\n", INTERPHONE_VERSION, BOARD_NAME);
  Serial.printf("pins: relay=%d led=%d buzzer=%d button=%d\n", PIN_RELAY, PIN_LED, PIN_BUZZER, PIN_BUTTON);

  pinMode(PIN_RELAY, OUTPUT);
  pinMode(PIN_LED, OUTPUT);
  pinMode(PIN_BUZZER, OUTPUT);
  pinMode(PIN_BUTTON, INPUT_PULLUP);  // external 10k pull-up is also on the board; both is fine
  digitalWrite(PIN_RELAY, !RELAY_ACTIVE_LEVEL);
  digitalWrite(PIN_BUZZER, !BUZZER_ACTIVE_LEVEL);

  ctl.begin(millis());
  net.begin();
  Serial.println("keys: u=unlock  d=deny  s=status");
}

void loop() {
  const uint32_t now = millis();

  // inputs
  ctl.setButtonRaw(digitalRead(PIN_BUTTON) == BUTTON_PRESSED_LEVEL, now);
  handleSerial();
  ctl.setOnline(net.online());
  DeviceCommand cmd;
  while (net.nextCommand(cmd)) {
    Serial.printf("[net] command %s (%s)\n", cmd.action, cmd.id);
    if (strcmp(cmd.action, "unlock") == 0) ctl.requestUnlock();
    else if (strcmp(cmd.action, "deny") == 0) ctl.requestDeny();
  }

  // logic
  const door::Outputs out = ctl.tick(now);
  if (out.sound != door::Sound::None) buzzer.play(out.sound, now);

  // outputs
  digitalWrite(PIN_RELAY, out.relay ? RELAY_ACTIVE_LEVEL : !RELAY_ACTIVE_LEVEL);
  digitalWrite(PIN_LED, out.led ? HIGH : LOW);
  digitalWrite(PIN_BUZZER, buzzer.tick(now) ? BUZZER_ACTIVE_LEVEL : !BUZZER_ACTIVE_LEVEL);

  if (ctl.state() != last_state) {
    last_state = ctl.state();
    net.reportState(door::stateName(last_state));
    Serial.printf("[door] -> %s\n", door::stateName(last_state));
  }
  delay(1);
}

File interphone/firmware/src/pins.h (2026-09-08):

// Pin map for the interphone door controller.
// Select the board with -DBOARD_DEVKIT_V1 (default) or -DBOARD_ESP32_S3 in platformio.ini.
// Source: docs/PROJECT_CONTEXT.md section 4.
#pragma once

#if defined(BOARD_ESP32_S3)
// ESP32-S3-DevKitC-1 (original design). Plain I/O, no strapping/USB/PSRAM conflicts.
#define PIN_RELAY    5   // KY-019 IN
#define PIN_LED      6   // status LED via 330R
#define PIN_BUZZER  18   // 1k into NPN base, low-side switch for the buzzer
#define PIN_BUTTON  21   // pushbutton to GND, 10k pull-up to 3V3 (active low)
#define BOARD_NAME "esp32-s3-devkitc-1"

#else
// ESP32 DevKit V1, 30-pin WROOM-32 (the board on the shopping list).
// Avoid GPIO6-11 (flash), GPIO0/2/12/15 (strapping); GPIO34-39 are input only.
#ifndef BOARD_DEVKIT_V1
#define BOARD_DEVKIT_V1
#endif
#define PIN_RELAY   13
#define PIN_LED     19
#define PIN_BUZZER  18
#define PIN_BUTTON  21
#define BOARD_NAME "esp32-devkit-v1"
#endif

// Electrical conventions (same on both boards)
#define RELAY_ACTIVE_LEVEL   HIGH   // KY-019 with NPN input: IN high = coil energised
#define BUZZER_ACTIVE_LEVEL  HIGH   // GPIO high -> NPN on -> active buzzer sounds
#define BUTTON_PRESSED_LEVEL LOW    // pull-up, button shorts to GND

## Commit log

2026-09-08 Add interphone software and hardware project
    [Component List.xlsx, Interphone Project one.fzz, Interphone Project two.fzz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]
2026-09-09 Update interphone 3 2.fzz
    [interphone 3 2.fzz]
2026-09-09 Fix ESP32 firmware networking and secrets
    This commit adds support for local credentials via src/secrets.h, ignores that file in git, and increases the ESP32 upload speed. It also fixes HTTP JSON parsing by reading the full response before deserializing, which avoids chunked-transfer issues from Supabase edge responses. The legacy Fritzing design files were also moved into a dedicated fritzing versions/ folder.
    [Interphone Project one.fzz, Interphone Project two.fzz, interphone 3 2.fzz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]
